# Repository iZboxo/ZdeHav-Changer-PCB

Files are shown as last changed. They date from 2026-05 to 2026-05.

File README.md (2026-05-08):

# ZdeHavCANdesignTCHG

> **Klipper CAN toolhead board — STM32G0B1CBT6 + TMC2209**

Custom toolhead board design for Klipper-based 3D printers. The board communicates over CAN bus and is designed for direct mounting on the print head (toolchanger or standard mount).

---

## Photos

<table>
  <tr>
    <td></td>
    <td></td>
    <td></td>
  </tr>
</table>

---

## Overview

https://izboxo.github.io/ZdeHav-Changer-PCB/bom/ibom.html

| Parameter | Value |
|---|---|
| MCU | STM32G0B1CBT6 (Cortex-M0+, 64 MHz, 128 KB Flash, LQFP-48) |
| CAN transceiver | SN65HVD230 (3.3 V, 1 Mbit/s, SOIC-8) |
| Stepper driver | TMC2209 (UART) |
| USB | USB-C (D+ / D−, DFU support) |
| Power input | 5 V via USB-C |
| Logic voltage | 3.3 V |
| Crystal | 16 MHz / 10 pF (HSE) |
| PCB | 4-layer |
| Schematic rev. | 1.0 (2026-02-02) |
| Firmware | Klipper (CANBUS UUID) |

---

## Features

- **CAN bus** — SN65HVD230, 120 Ω termination resistor (R26), slope-control resistor on RS pin
- **TMC2209** — STEP / DIR / EN / DIAG, UART via USART2 (`USART2_TX_2209_PDN`), SpreadCycle/StealthChop
- **Thermistors** — 3× ADC inputs (THERM-1, THERM-2, THERM-3)
- **Heater** — PWM output (`TIM3_HE`) for hotend heater
- **Fan** — PWM output (`TIM3_FAN`) for part cooling fan
- **NeoPixel** — 1× WS2812B-Mini (5 V), GPIO output `GPIO_NEOPIXEL`
- **Piezo buzzer** — GPIO output `GPIO_PIEZO` via dedicated subsheet
- **SWD** — SWDIO / SWCLK for debug (Black Magic Probe / J-Link)
- **BOOT0** — SPDT switch (SW1) for toggling DFU / normal boot
- **Filtered VREF** — ferrite bead (FB1) + bypass capacitor array (C1–C8) for clean analog VREF

---

## Schematic Structure

| Sheet | File | Contents |
|---|---|---|
| Main | `ZdeHavCANdesignTCHG.kicad_sch` | MCU, CAN transceiver, crystal, NeoPixel, SWD, BOOT0 |
| Power | `usbc.kicad_sch` | USB-C connector, 5 V / 3.3 V power, CAN input |
| Piezo | `piezo.kicad_sch` | Piezo buzzer and driver |
| Extruder | `extruder.kicad_sch` | TMC2209, extruder connector |
| TH+HT | `thermistorsandheaters.kicad_sch` | Thermistors (3×), heater, fan MOSFETs |

---

## Pinout MCU (key functions)

| STM32 Pin | Function |
|---|---|
| PD0 | FDCAN1_RX |
| PD1 | FDCAN1_TX |
| PA0 / PA1 | ADC1_IN0 / ADC1_IN1 (THERM-1, THERM-2) |
| PC6 | TIM3_CH1 — heater PWM |
| PC7 | TIM3_CH2 — fan PWM |
| PA13 / PA14 | SWDIO / SWCLK (SWD) |
| PA14 / BOOT0 | BOOT0 (switch SW1) |
| PF0 / PF1 | HSE IN / OUT (16 MHz crystal) |

> See schematic for full pin mapping.

---

## Firmware — Klipper

The board is intended to run as a Klipper CAN node.

Example `printer.cfg` snippet:

```ini
[mcu head0]
canbus_uuid: <YOUR_UUID_HERE>

[extruder]
step_pin: head0:PD1
dir_pin: head0:PD0
# ... fill in remaining pins per your wiring

[temperature_sensor toolhead_NTC]
sensor_type: NTC 100K MGB18-104F39050L32
sensor_pin: head0:PA0
```

---

## Manufacturing

A ready-to-order fabrication archive **`CANTCHG28.zip`** is available in the project files. This file is specifically prepared for **JLCPCB** (4-layer stackup) and contains all necessary files (Gerber, BOM, CPL) for production.

---
## Dependencies

- [KiCad 9.0](https://www.kicad.org/)
- [Klipper firmware](https://github.com/Klipper3d/klipper)

---

## License

This hardware design is released as open-source under the **MIT** license.

---

*Design: Zdeněk Havlát — [zdehav.cz](https://zdehav.cz)*

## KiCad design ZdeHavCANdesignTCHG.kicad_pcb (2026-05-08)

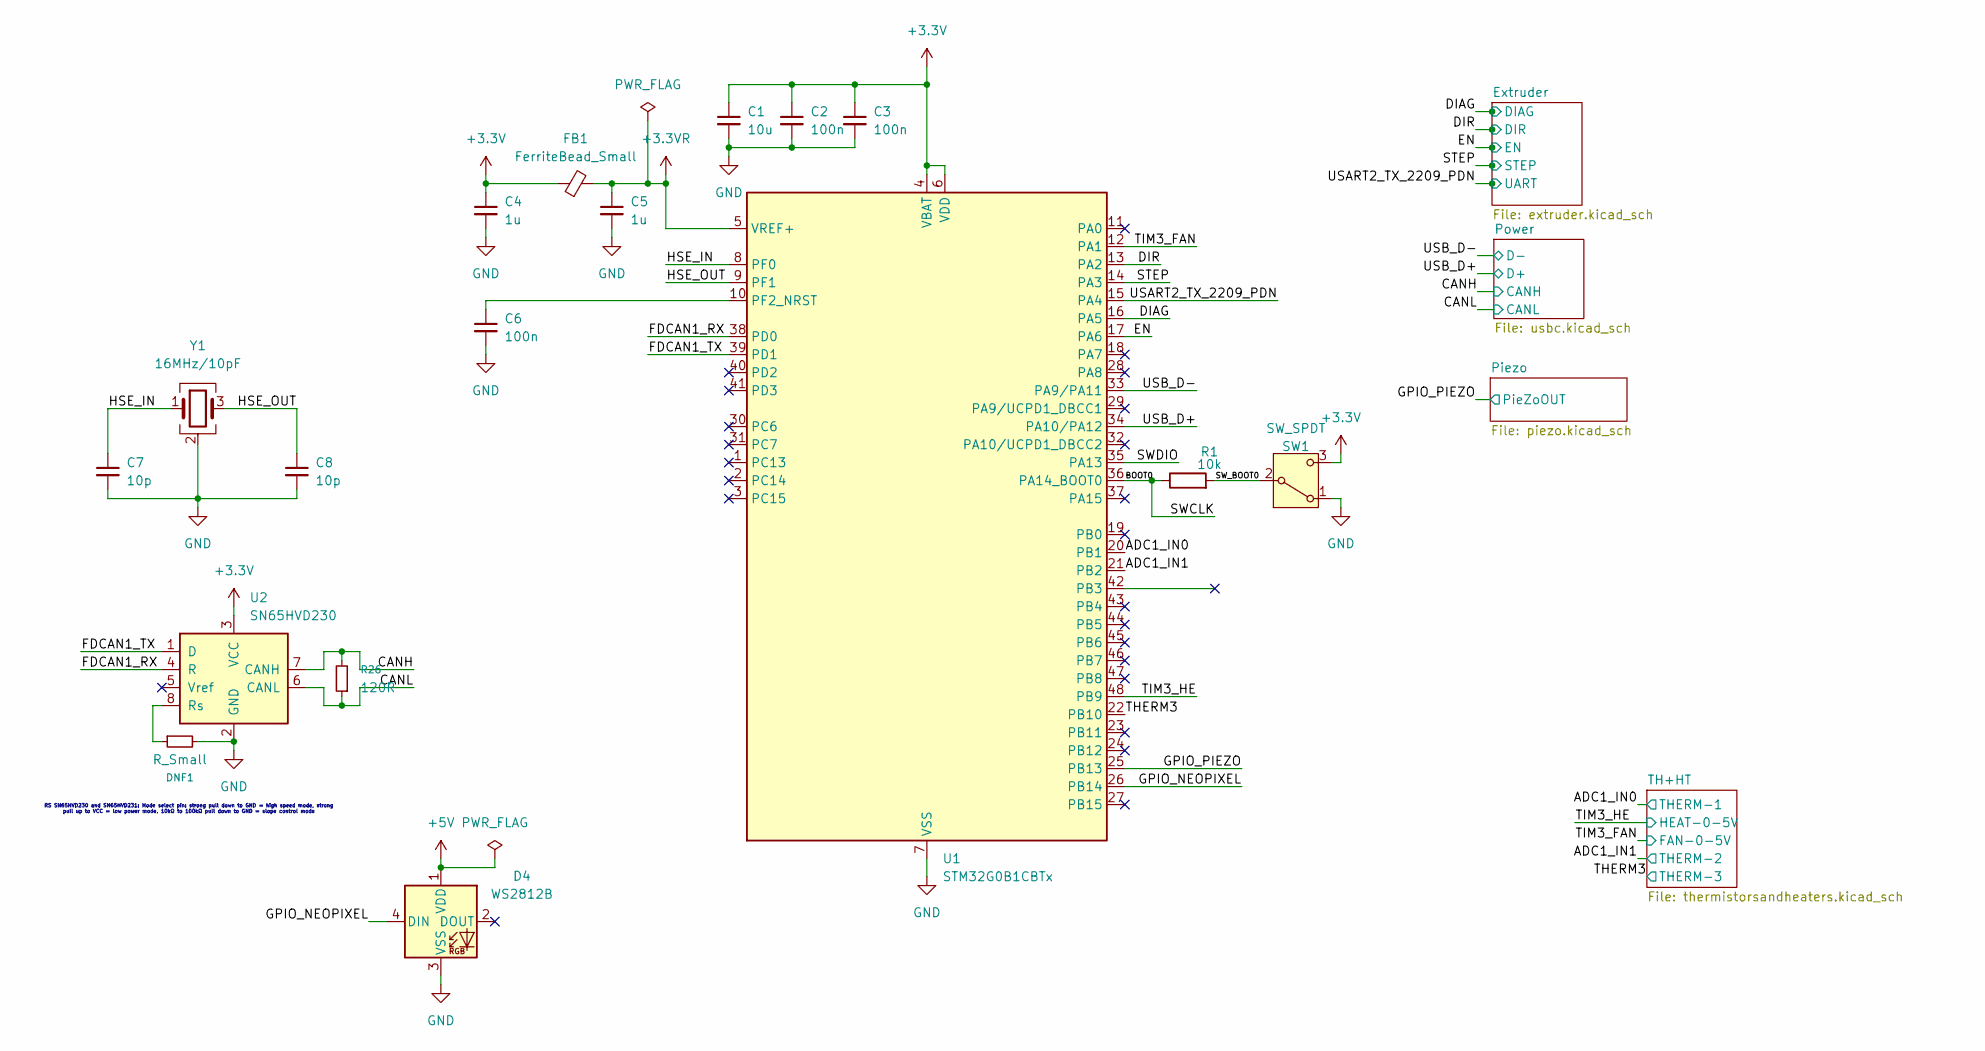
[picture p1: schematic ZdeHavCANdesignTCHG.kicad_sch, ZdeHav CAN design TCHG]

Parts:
C1: 10u; C_0603_1608Metric_Pad1.08x0.95mm_HandSolder
C2, C3, C6: 100n; C_0603_1608Metric_Pad1.08x0.95mm_HandSolder
C4, C5: 1u; C_0603_1608Metric_Pad1.08x0.95mm_HandSolder
C7, C8: 10p; C_0603_1608Metric_Pad1.08x0.95mm_HandSolder
D4: WS2812B; LED_WS2812B-Mini_PLCC4_3.5x3.5mm
DNF1: R_Small; R_0603_1608Metric_Pad0.98x0.95mm_HandSolder
FB1: FerriteBead_Small; L_0603_1608Metric_Pad1.05x0.95mm_HandSolder
R1: 10k; R_0603_1608Metric_Pad0.98x0.95mm_HandSolder
R26: 120R; R_0603_1608Metric_Pad0.98x0.95mm_HandSolder
SW1: SW_SPDT; PinHeader_1x03_P1.00mm_Vertical
U1: STM32G0B1CBTx; LQFP-48_7x7mm_P0.5mm
U2: SN65HVD230; SOIC-8_3.9x4.9mm_P1.27mm
Y1: 16MHz/10pF; LFXTAL071255CUTT

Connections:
+3.3V: C1.1, C2.1, C3.1, C4.1, FB1.1, SW1.3 (C), U1.4 (VBAT), U1.6 (VDD), U2.3 (VCC); also elsewhere on the board
+3.3VR: C5.1, FB1.2, U1.5 (VREF+)
+5V: D4.1 (VDD); also elsewhere on the board
/ADC1_IN0: U1.20 (PB1); also elsewhere on the board
/ADC1_IN1: U1.21 (PB2); also elsewhere on the board
/BOOT0: R1.1, U1.36 (PA14_BOOT0)
/CANH: R26.2, U2.7 (CANH); also elsewhere on the board
/CANL: R26.1, U2.6 (CANL); also elsewhere on the board
/DIAG: U1.16 (PA5); also elsewhere on the board
/DIR: U1.13 (PA2); also elsewhere on the board
/EN: U1.17 (PA6); also elsewhere on the board
/FDCAN1_RX: U1.38 (PD0), U2.4 (R)
/FDCAN1_TX: U1.39 (PD1), U2.1 (D)
/GPIO_NEOPIXEL: D4.4 (DIN), U1.26 (PB14)
/GPIO_PIEZO: U1.25 (PB13); also elsewhere on the board
/HSE_IN: C7.1, U1.8 (PF0), Y1.1
/HSE_OUT: C8.1, U1.9 (PF1), Y1.3
/STEP: U1.14 (PA3); also elsewhere on the board
/SWDIO: U1.35 (PA13)
/SW_BOOT0: R1.2, SW1.2 (B)
/THERM3: U1.22 (PB10); also elsewhere on the board
/TIM3_FAN: U1.12 (PA1); also elsewhere on the board
/TIM3_HE: U1.48 (PB9); also elsewhere on the board
/USART2_TX_2209_PDN: U1.15 (PA4); also elsewhere on the board
/USB_D+: U1.34 (PA10/PA12); also elsewhere on the board
/USB_D-: U1.33 (PA9/PA11); also elsewhere on the board
GND: C1.2, C2.2, C3.2, C4.2, C5.2, C6.2, C7.2, C8.2, D4.3 (VSS), DNF1.2, SW1.1 (A), U1.7 (VSS), U2.2 (GND), Y1.2 (G), Y1.4 (G); also elsewhere on the board
unnamed: C6.1, U1.10 (PF2_NRST)
unnamed: DNF1.1, U2.8 (Rs)

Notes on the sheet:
RS SN65HVD230 and SN65HVD231: Mode select pin: strong pull down to GND = high speed mode, strong pull up to VCC = low power mode, 10kΩ to 100kΩ pull down to GND = slope control mode

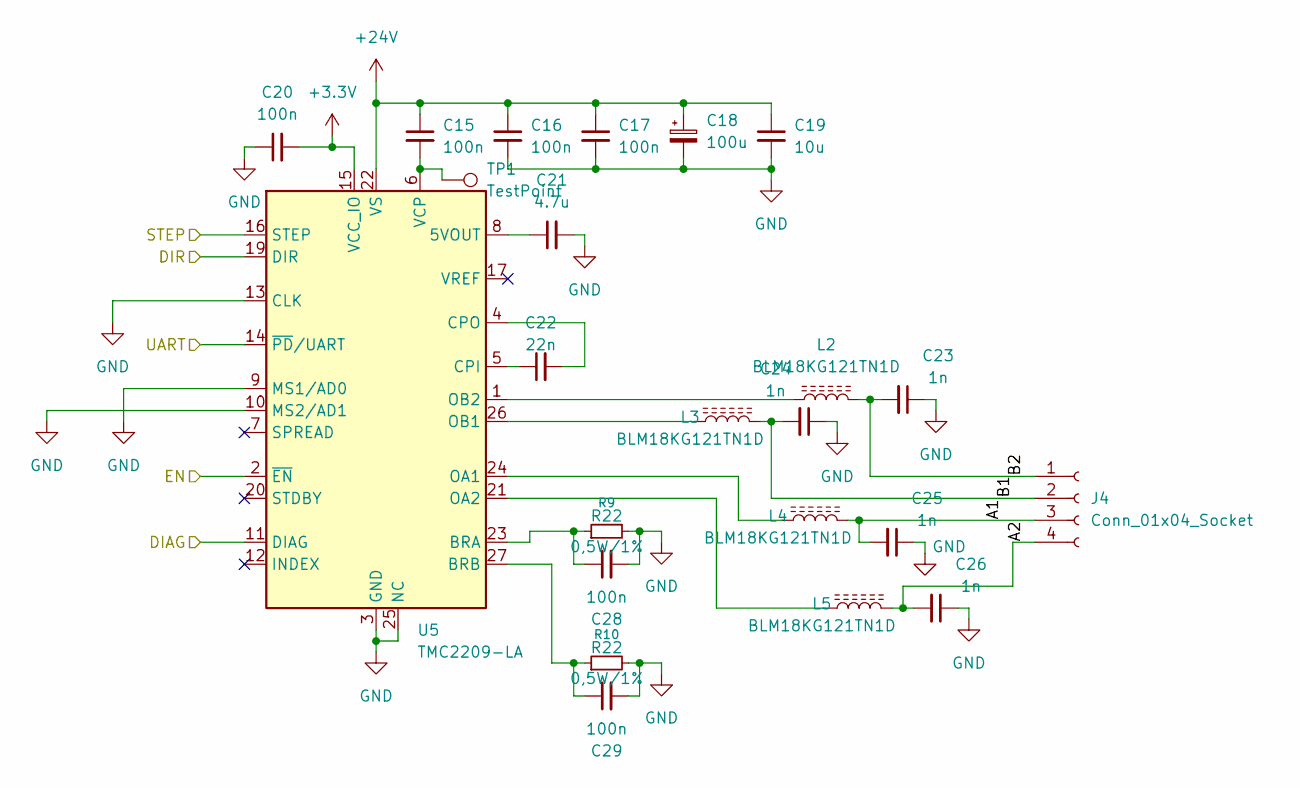
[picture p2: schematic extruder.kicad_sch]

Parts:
C15, C16, C17, C20, C28, C29: 100n; C_0603_1608Metric_Pad1.08x0.95mm_HandSolder
C18: 100u; C_Elec_6.3x7.7
C19: 10u; C_1206_3216Metric_Pad1.33x1.80mm_HandSolder
C21: 4.7u; C_0603_1608Metric_Pad1.08x0.95mm_HandSolder
C22: 22n; C_0603_1608Metric_Pad1.08x0.95mm_HandSolder
C23, C24, C25, C26: 1n; C_0603_1608Metric_Pad1.08x0.95mm_HandSolder
J4: Conn_01x04_Socket; JST_XH_B4B-XH-A_1x04_P2.50mm_Vertical
L2, L3, L4, L5: BLM18KG121TN1D; L_0603_1608Metric_Pad1.05x0.95mm_HandSolder
R9, R10: R22; R_1206_3216Metric_Pad1.30x1.75mm_HandSolder
TP1: TestPoint; TestPoint_Pad_D1.0mm
U5: TMC2209-LA; VQFN-28-1EP_5x5mm_P0.5mm_EP3.7x3.7mm_ThermalVias

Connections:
+3.3V: C20.2, U5.15 (VCC_IO); also elsewhere on the board
+24V: C15.1, C16.1, C17.1, C18.1, C19.1, U5.22 (VS), U5.28 (VS); also elsewhere on the board
/DIAG: U5.11 (DIAG); also elsewhere on the board
/DIR: U5.19 (DIR); also elsewhere on the board
/EN: U5.2 (~EN); also elsewhere on the board
/Extruder/A1: C25.2, J4.3, L4.2
/Extruder/A2: C26.2, J4.4, L5.2
/Extruder/B1: C24.2, J4.2, L3.2
/Extruder/B2: C23.2, J4.1, L2.2
/STEP: U5.16 (STEP); also elsewhere on the board
/USART2_TX_2209_PDN: U5.14 (~PD/UART); also elsewhere on the board
GND: C16.2, C17.2, C18.2, C19.2, C20.1, C21.2, C23.1, C24.1, C25.1, C26.1, C28.2, C29.2, R9.2, R10.2, U5.3 (GND), U5.9 (MS1/AD0), U5.10 (MS2/AD1), U5.13 (CLK), U5.18 (GND), U5.25 (NC), U5.29 (GND); also elsewhere on the board
unnamed: C21.1, U5.8 (5VOUT)
unnamed: C28.1, R9.1, U5.23 (BRA)
unnamed: C29.1, R10.1, U5.27 (BRB)
unnamed: C22.1, U5.5 (CPI)
unnamed: C22.2, U5.4 (CPO)
unnamed: L4.1, U5.24 (OA1)
unnamed: L5.1, U5.21 (OA2)
unnamed: L3.1, U5.26 (OB1)
unnamed: L2.1, U5.1 (OB2)
unnamed: C15.2, TP1.1, U5.6 (VCP)

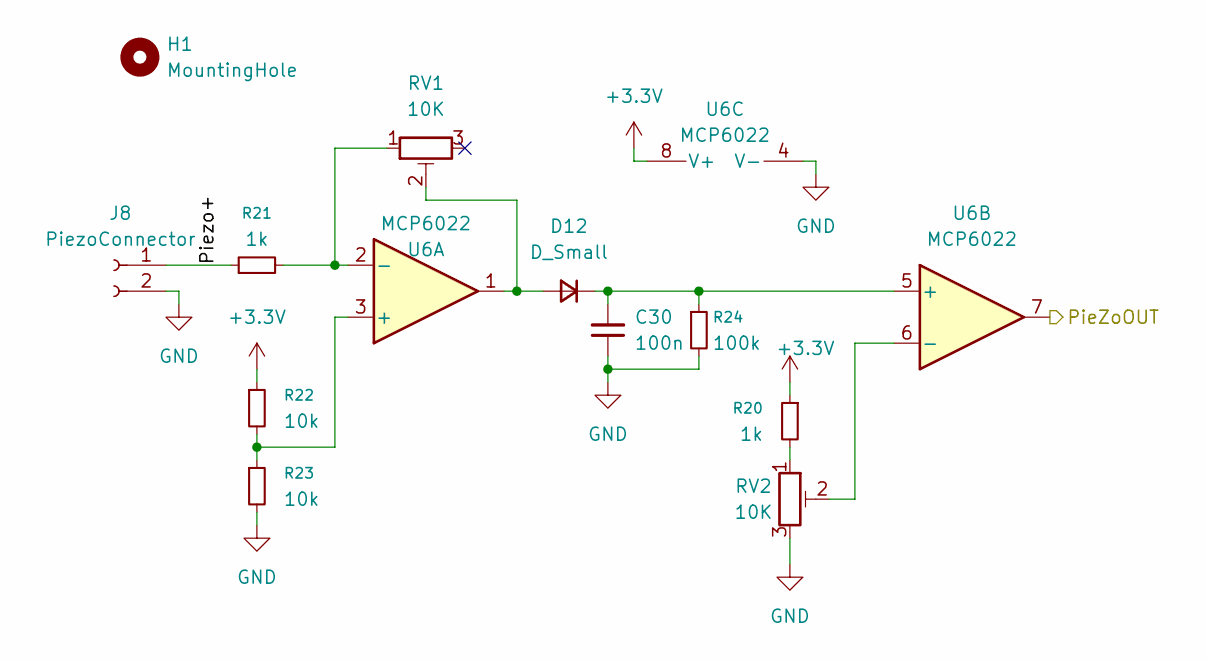
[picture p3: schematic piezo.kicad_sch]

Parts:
C30: 100n; C_0603_1608Metric_Pad1.08x0.95mm_HandSolder
D12: D_Small; D_0603_1608Metric_Pad1.05x0.95mm_HandSolder
H1: MountingHole; MountingHole_2.2mm_M2_Pad_Via
J8: PiezoConnector; JST_XH_B2B-XH-A_1x02_P2.50mm_Vertical
R20, R21: 1k; R_0603_1608Metric_Pad0.98x0.95mm_HandSolder
R22, R23: 10k; R_0603_1608Metric_Pad0.98x0.95mm_HandSolder
R24: 100k; R_0603_1608Metric_Pad0.98x0.95mm_HandSolder
RV1, RV2: 10K; Trimmer 10k 3305SMD
U6: MCP6022; TSSOP-8_4.4x3mm_P0.65mm

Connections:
+3.3V: R20.1, R22.1, U6.8 (V+); also elsewhere on the board
/GPIO_PIEZO: U6.7; also elsewhere on the board
/Piezo/Piezo+: J8.1, R21.1
GND: C30.1, J8.2, R23.2, R24.2, RV2.3, U6.4 (V-); also elsewhere on the board
unnamed: D12.2 (A), RV1.2, U6.1
unnamed: C30.2, D12.1 (K), R24.1, U6.5 (+)
unnamed: R20.2, RV2.1
unnamed: R22.2, R23.1, U6.3 (+)
unnamed: R21.2, RV1.1, U6.2 (-)
unnamed: RV2.2, U6.6 (-)

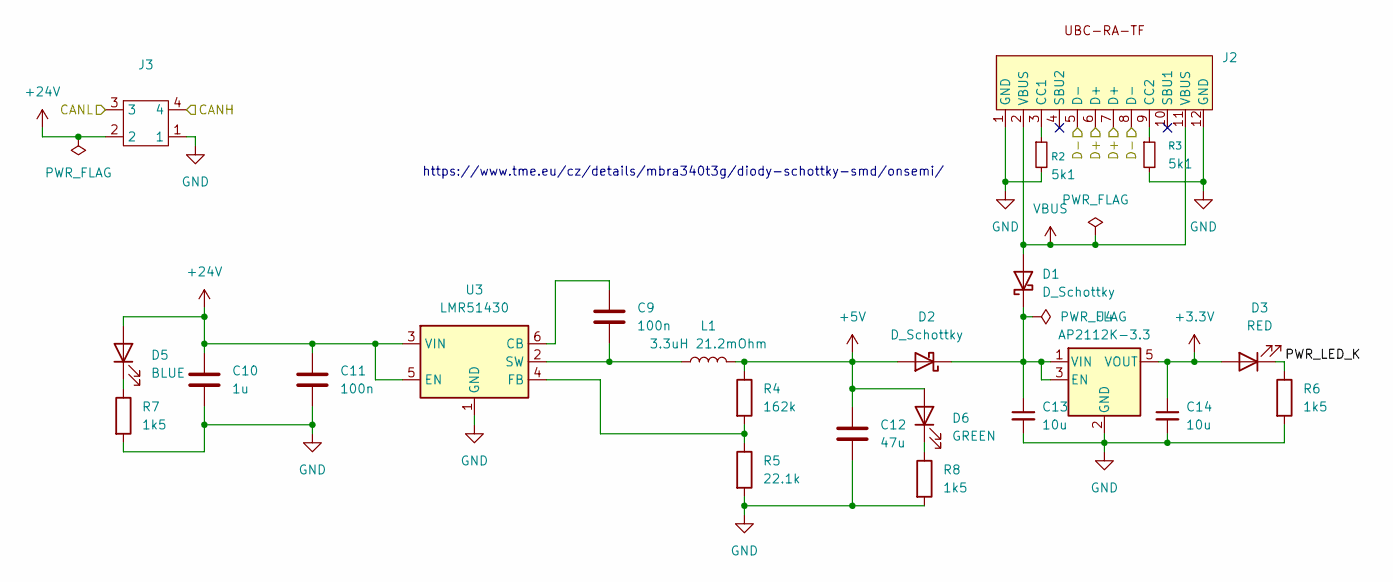
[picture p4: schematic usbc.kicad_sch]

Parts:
C9, C11: 100n; C_0603_1608Metric_Pad1.08x0.95mm_HandSolder
C10: 1u; C_0603_1608Metric_Pad1.08x0.95mm_HandSolder
C12: 47u; C_0603_1608Metric_Pad1.08x0.95mm_HandSolder
C13, C14: 10u; C_0603_1608Metric_Pad1.08x0.95mm_HandSolder
D1, D2: D_Schottky; D_SOD-323_HandSoldering
D3: RED; LED_0603_1608Metric_Pad1.05x0.95mm_HandSolder
D5: BLUE; LED_0603_1608Metric_Pad1.05x0.95mm_HandSolder
D6: GREEN; LED_0603_1608Metric_Pad1.05x0.95mm_HandSolder
J2: USBC
J3: Molex Micro-Fit 3.0 4
L1: 3.3uH 21.2mOhm; SD53
R2, R3: 5k1; R_0603_1608Metric_Pad0.98x0.95mm_HandSolder
R4: 162k; R_0603_1608Metric_Pad0.98x0.95mm_HandSolder
R5: 22.1k; R_0603_1608Metric_Pad0.98x0.95mm_HandSolder
R6, R7, R8: 1k5; R_0603_1608Metric_Pad0.98x0.95mm_HandSolder
U3: LMR51430; SOT-23-6
U4: AP2112K-3.3; SOT-23-5

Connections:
+3.3V: C14.1, D3.2 (A), U4.5 (VOUT); also elsewhere on the board
+5V: C12.1, D2.2 (A), D6.2 (A), L1.2, R4.1; also elsewhere on the board
+24V: C10.1, C11.1, D5.2 (A), J3.2, U3.3 (VIN), U3.5 (EN); also elsewhere on the board
/CANH: J3.4; also elsewhere on the board
/CANL: J3.3; also elsewhere on the board
/Power/PWR_LED_K: D3.1 (K), R6.1
/USB_D+: J2.6 (D+), J2.7 (D+); also elsewhere on the board
/USB_D-: J2.5 (D-), J2.8 (D-); also elsewhere on the board
GND: C10.2, C11.2, C12.2, C13.2, C14.2, J2.1 (GND), J2.12 (GND), J3.1, R2.2, R3.2, R5.2, R6.2, R7.2, R8.2, U3.1 (GND), U4.2 (GND); also elsewhere on the board
unnamed: C13.1, D1.1 (K), D2.1 (K), U4.1 (VIN), U4.3 (EN)
unnamed: D5.1 (K), R7.1
unnamed: D6.1 (K), R8.1
unnamed: J2.3 (CC1), R2.1
unnamed: J2.9 (CC2), R3.1
unnamed: C9.2, U3.6 (CB)
unnamed: R4.2, R5.1, U3.4 (FB)
unnamed: C9.1, L1.1, U3.2 (SW)
VBUS: D1.2 (A), J2.2 (VBUS), J2.11 (VBUS)

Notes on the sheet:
https://www.tme.eu/cz/details/mbra340t3g/diody-schottky-smd/onsemi/

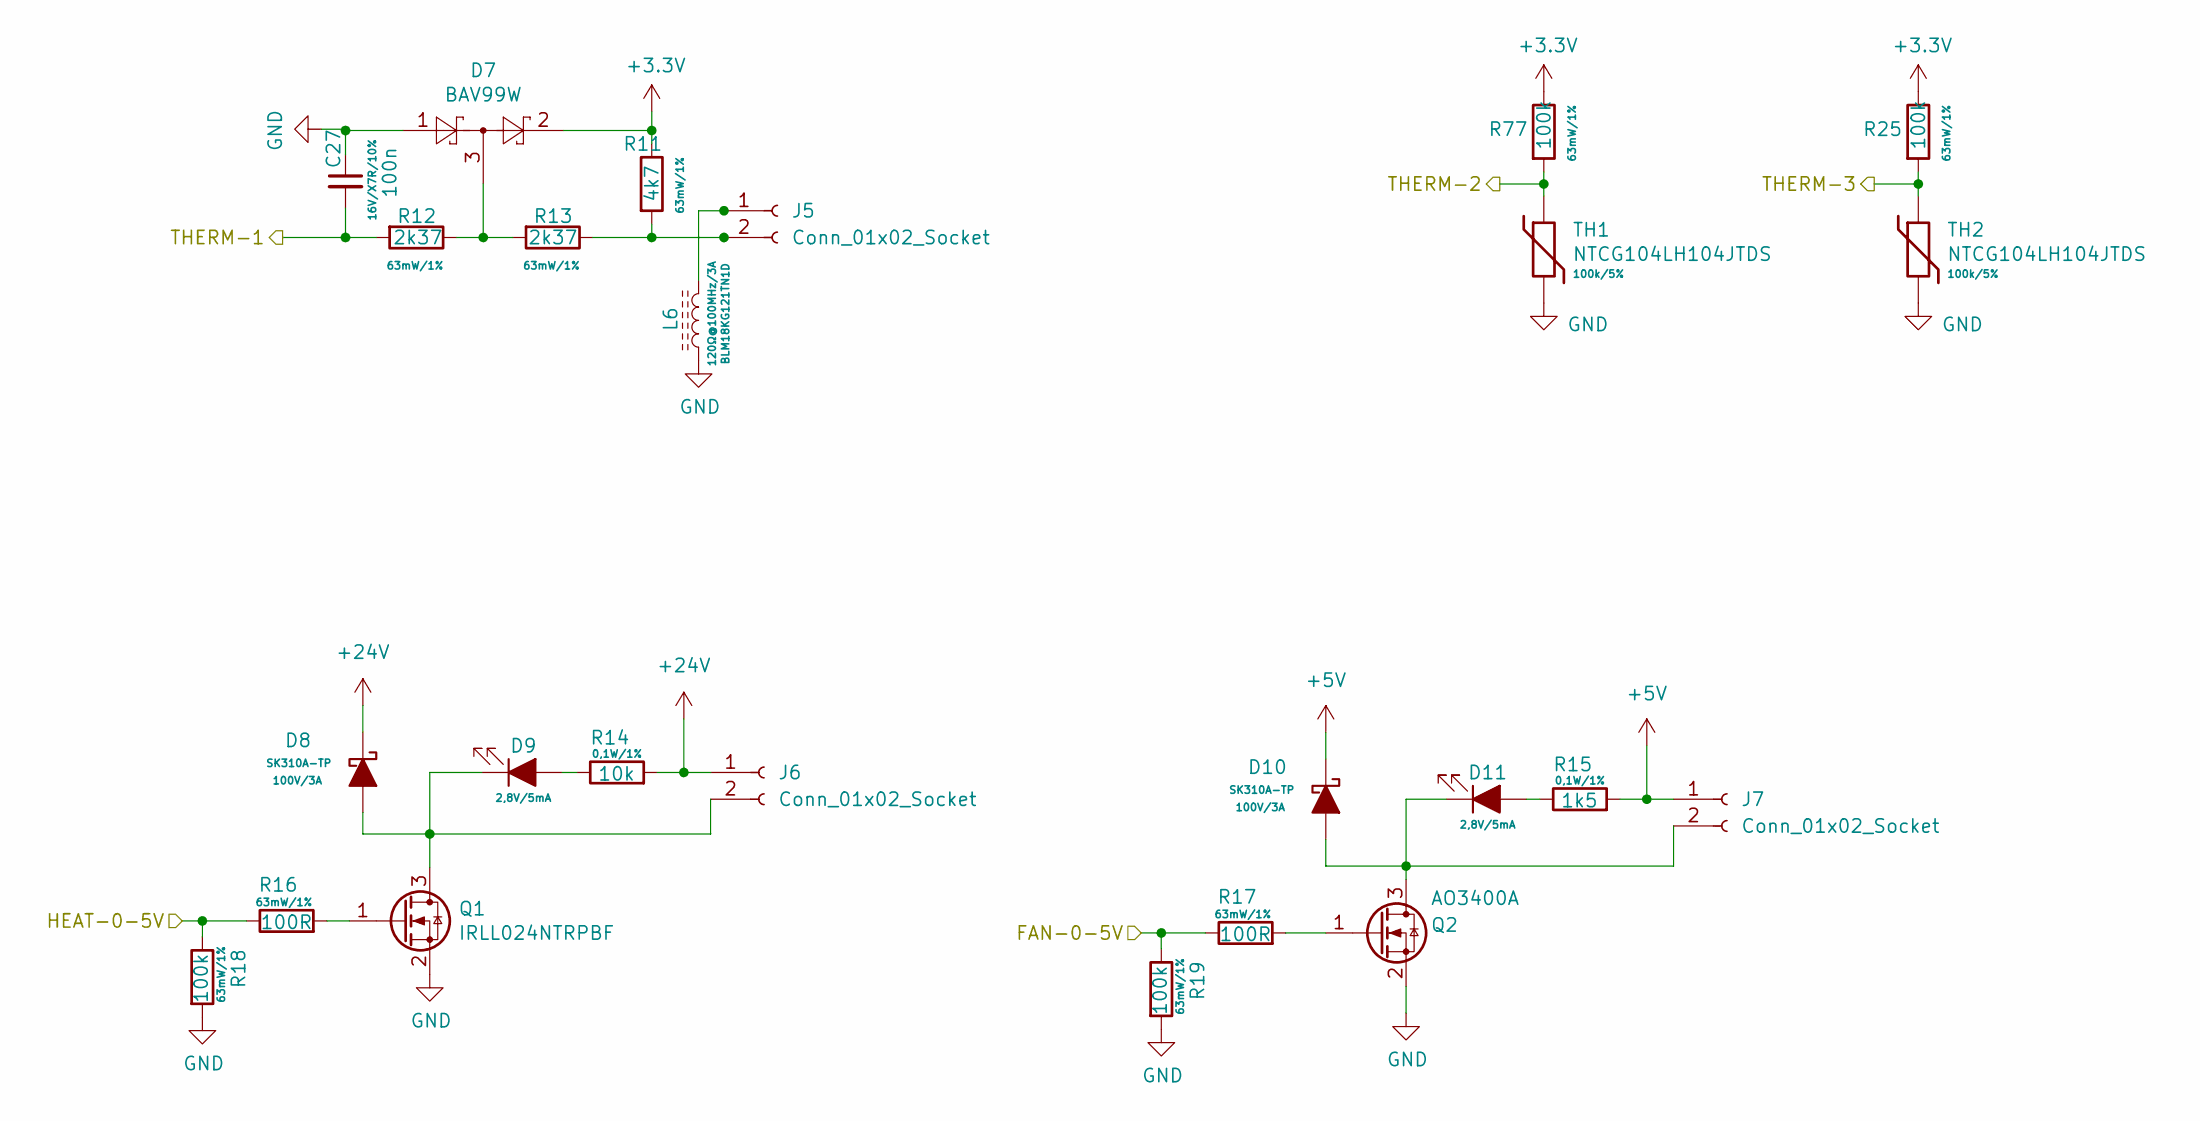
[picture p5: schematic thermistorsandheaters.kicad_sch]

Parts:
C27: 100n; C_0603_1608Metric_Pad1.08x0.95mm_HandSolder
D7: BAV99W; SOT-323_SC-70
D8: SK310A-TP; D_SMA
D9, D11: GRN; LED_0603_1608Metric_Pad1.05x0.95mm_HandSolder
D10: SK310A-TP; D_SOD-323_HandSoldering
J5, J6, J7: Conn_01x02_Socket; JST_XH_B2B-XH-A_1x02_P2.50mm_Vertical
L6: BLM18KG121TN1D; L_0603_1608Metric_Pad1.05x0.95mm_HandSolder
Q1: IRLL024NTRPBF; SOT-223-3_TabPin2
Q2: AO3400A; SOT-23
R11: 4k7; R_0603_1608Metric_Pad0.98x0.95mm_HandSolder
R12, R13: 2k37; R_0603_1608Metric_Pad0.98x0.95mm_HandSolder
R14: 10k; R_0603_1608Metric_Pad0.98x0.95mm_HandSolder
R15: 1k5; R_0603_1608Metric_Pad0.98x0.95mm_HandSolder
R16, R17: 100R; R_0603_1608Metric_Pad0.98x0.95mm_HandSolder
R18, R19, R25, R77: 100k; R_0603_1608Metric_Pad0.98x0.95mm_HandSolder
TH1, TH2: NTCG104LH104JTDS; R_0603_1608Metric_Pad0.98x0.95mm_HandSolder

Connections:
+3.3V: D7.2, R11.1, R25.1, R77.1; also elsewhere on the board
+5V: D10.1 (K), J7.1, R15.2; also elsewhere on the board
+24V: D8.1 (K), J6.1, R14.2; also elsewhere on the board
/ADC1_IN0: C27.2, R12.2; also elsewhere on the board
/ADC1_IN1: R77.2, TH1.1; also elsewhere on the board
/THERM3: R25.2, TH2.1; also elsewhere on the board
/TIM3_FAN: R17.1, R19.1; also elsewhere on the board
/TIM3_HE: R16.1, R18.1; also elsewhere on the board
GND: C27.1, D7.1, L6.1, Q1.2 (S), Q2.2 (S), R18.2, R19.2, TH1.2, TH2.2; also elsewhere on the board
unnamed: D7.3, R12.1, R13.2
unnamed: D8.2 (A), D9.1 (K), J6.2, Q1.3 (D)
unnamed: D9.2 (A), R14.1
unnamed: D10.2 (A), D11.1 (K), J7.2, Q2.3 (D)
unnamed: D11.2 (A), R15.1
unnamed: J5.1, L6.2
unnamed: J5.2, R11.2, R13.1
unnamed: Q1.1 (G), R16.2
unnamed: Q2.1 (G), R17.2

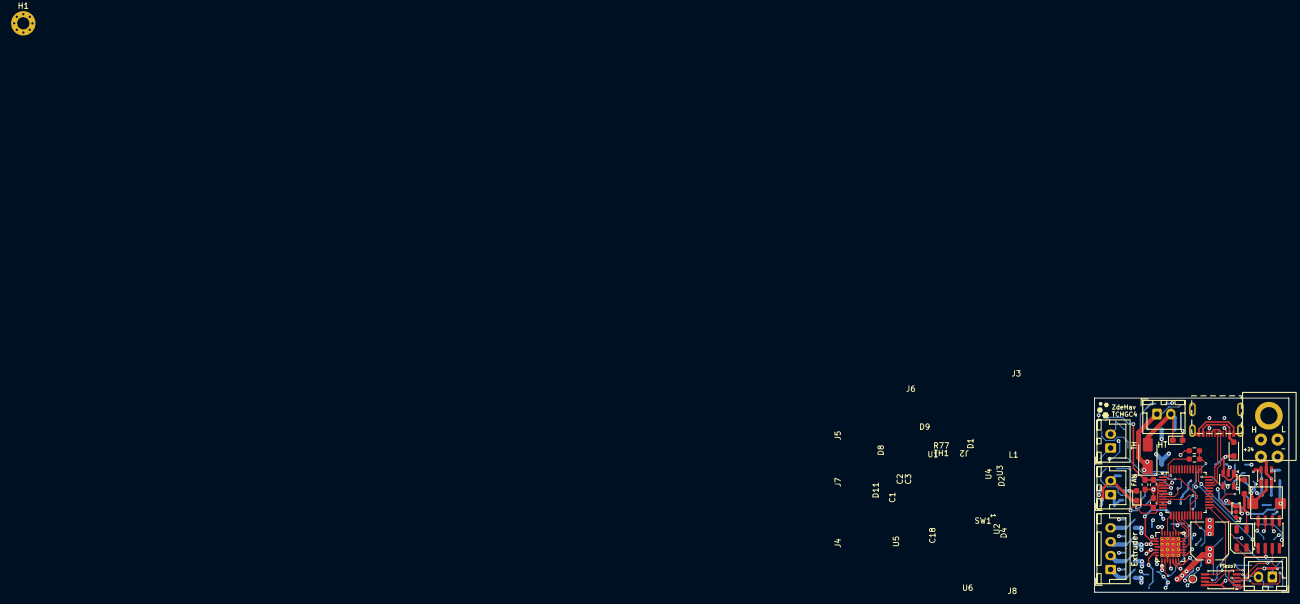
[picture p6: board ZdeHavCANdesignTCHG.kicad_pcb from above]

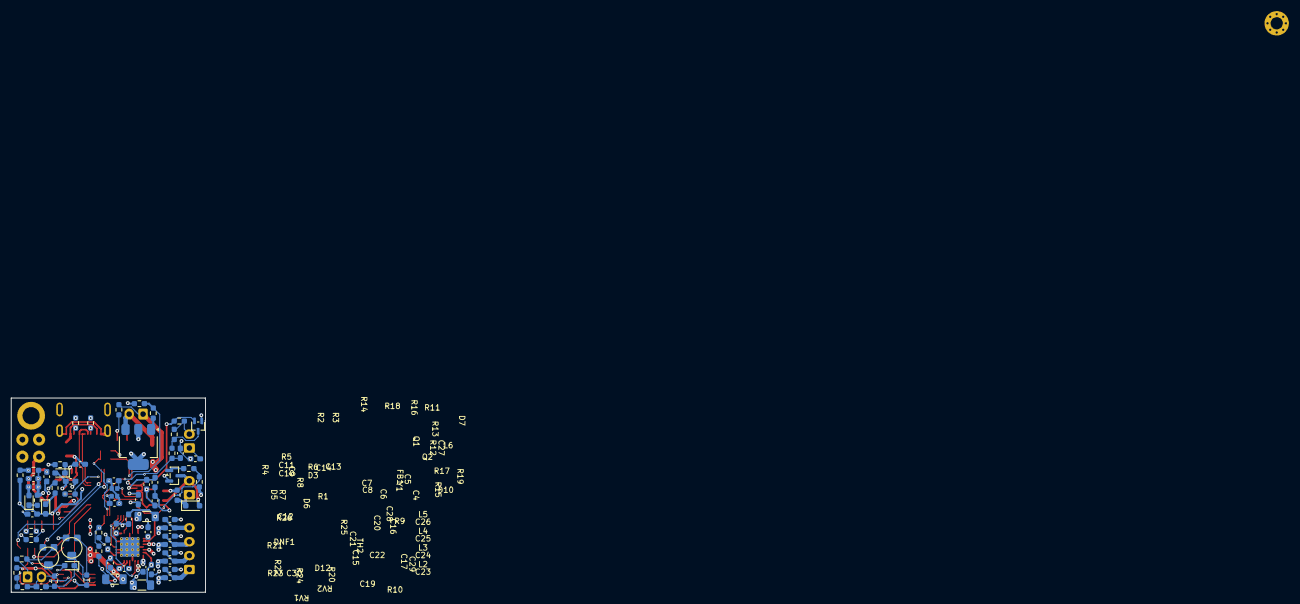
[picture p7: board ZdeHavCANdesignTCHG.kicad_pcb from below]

Board: 4 copper layers, 35.0 x 35.0 mm, 100 parts (71 on the bottom side), 69 nets.
